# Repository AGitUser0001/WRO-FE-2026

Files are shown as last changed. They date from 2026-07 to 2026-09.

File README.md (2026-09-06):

# Botzilla | WRO 2026 Future Engineers

> [!IMPORTANT]
> **Looking for the full engineering record, photographs, tests, and iterations?** Start with the [Engineering Journal index](docs/00-engineering-journal.md).

## Contents

- [Project abstract](#project-abstract)
- [Team](#team)
- [Challenge overview](#challenge-overview)
- [Requirements and constraints](#requirements-and-constraints)
- [Robot at a glance](#robot-at-a-glance)
- [Overall system architecture](#overall-system-architecture)
- [1. Mobility & Mechanical Design](#1-mobility--mechanical-design)
  - [Final architecture](#final-architecture)
  - [A. Chassis Design Choices](#a-chassis-design-choices)
  - [B. Steering and Drive Mechanism](#b-steering-and-drive-mechanism)
  - [C. Torque and Speed Reasoning](#drive-motor-torque-and-speed)
  - [D. Mechanical Stability and Rigidity](#d-mechanical-stability-and-rigidity)
  - [E. Design Trade-offs, Component Selection, and Iteration](#e-design-trade-offs-component-selection-and-iteration)
- [2. Power & Sensor Architecture](#2-power--sensor-architecture)
  - [A. Power Budget, One-Battery Architecture, and Evidence](#a-power-budget-one-battery-architecture-and-evidence)
  - [B. Sensor and Communication Trade-offs](#b-sensor-and-communication-trade-offs)
  - [C. Placement Proven Against Field Geometry](#c-placement-proven-against-field-geometry)
  - [D. Calibration and a Common Vehicle Coordinate Frame](#d-calibration-and-a-common-vehicle-coordinate-frame)
  - [E. Failure Points and Reliability Iterations](#e-failure-points-and-reliability-iterations)
- [3. Software Architecture & Obstacle Strategy](#software-architecture-obstacle-strategy)
  - [Software modules and runtime chain](#software-modules-runtime)
  - [Two challenge branches of the shared planner](#shared-planner-challenge-branches)
  - [Safety and edge cases](#software-safety-edge-cases)
  - [Parking scope statement](docs/09-parking-strategy.md)
- [4. Systems Thinking & Engineering Decisions](#systems-thinking-engineering-decisions)
  - [Decision record](#decision-record)
  - [Active risks and mitigations](#active-risks-mitigations)
- [5. Reproducibility & GitHub Quality](#reproducibility-github-quality)
  - [Reproduction path](#reproduction-path)
  - [Detailed linked documents](#detailed-document-index)
  - [Software quick start](#software-quick-start)
  - [Demonstration videos](#demonstration-videos)
  - [Current status](#current-status)
  - [License](#license)

---

## Project abstract

This repository documents Botzilla's vehicle for the 2026 World Robot Olympiad (WRO) Future Engineers competition.

---

## Team

**Institution:** Autopilot  
**Competition entry:** WRO Future Engineers, 16–19 years  
**Coach:** Lili Wang

| Team member | Age | Hobbies | Portrait |
|---|---:|---|---|
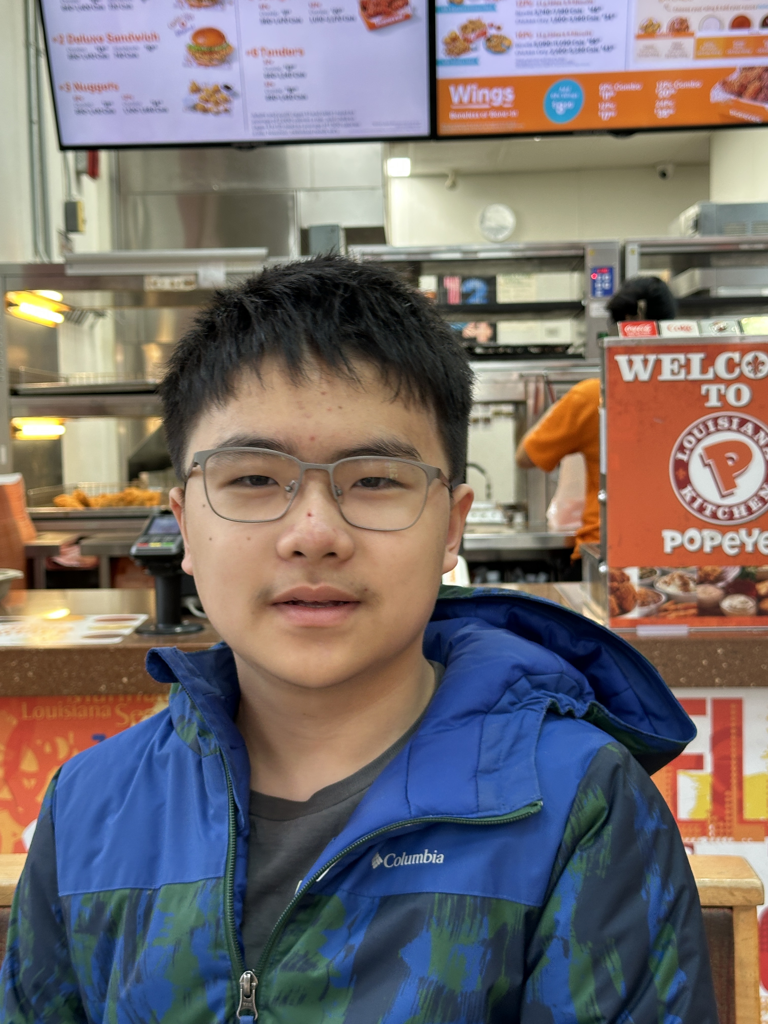
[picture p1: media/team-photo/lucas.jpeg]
Portrait of Lucas Zheng
| Lucas Zheng | 15 | Programming and photography |  |
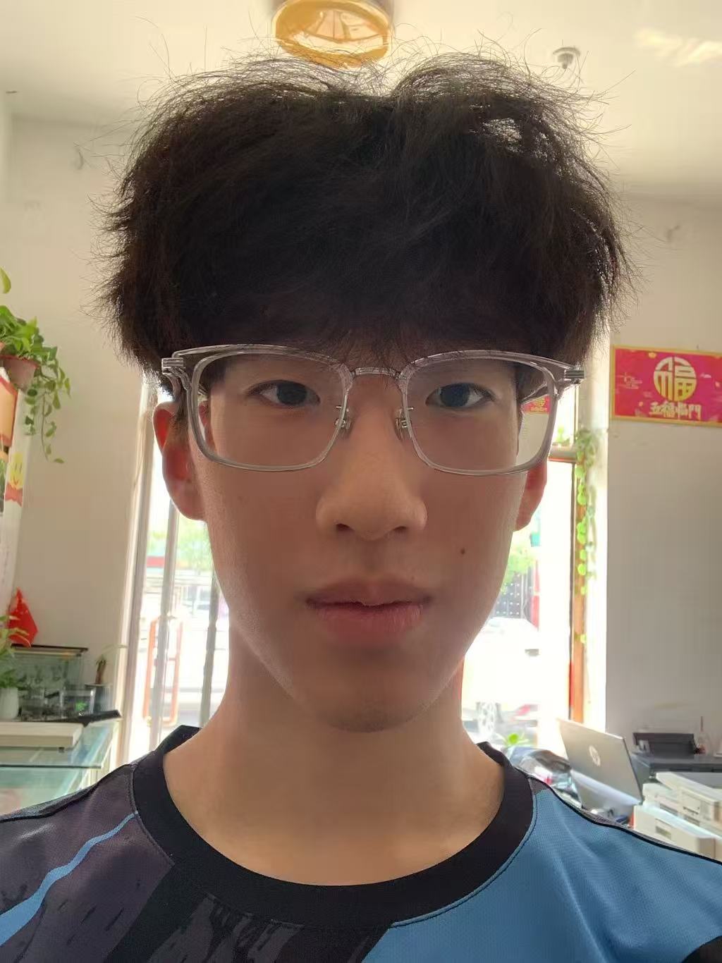
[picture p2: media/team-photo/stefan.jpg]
Portrait of Yueteng Ma
| Yueteng Ma | 16 | Badminton and mathematics |  |
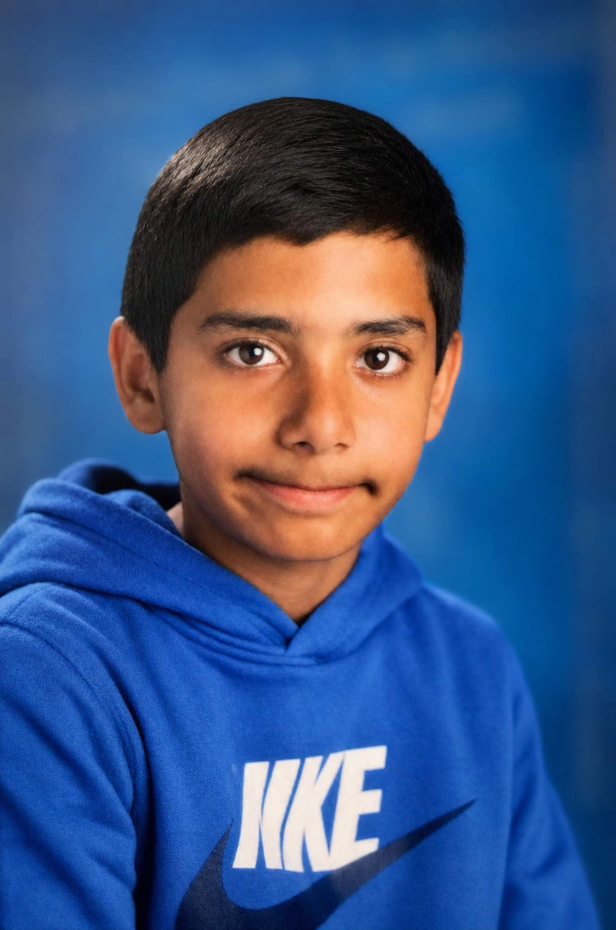
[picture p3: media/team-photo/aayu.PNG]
Portrait of Aayu Mattas
| Aayu Mattas | 14 | General sports and introductory robotics learning |  |

The coach supported learning and organization. The students designed, constructed, programmed, tested, and documented the vehicle.

> [!IMPORTANT]
> **Detailed engineering document:** [Team and Project](docs/01-team-and-project.md) — team identity, members, responsibilities, development method, and project scope.

---

## Challenge overview

### Open Challenge

The robot must complete three laps on the track after being placed randomly inside the walls of the track. One button turns on the robot and one button starts the program. After this, no further interactions with the robot are allowed. See the [Open Challenge Strategy](docs/07-open-challenge-strategy.md).

### Obstacle Challenge

The robot must complete three laps on the track with randomly arranged green and red traffic signs. It must pass on the right side of a red pillar and the left side of a green pillar. See the [Obstacle Challenge Strategy](docs/08-obstacle-challenge-strategy.md).

Learn about the challenges and rules [here](https://wro-association.org/wp-content/uploads/WRO-2026-Future-Engineers-Self-Driving-Cars-General-Rules.pdf).

---

## Requirements and constraints

Competition rules directly shape the vehicle's perception, mechanical, power, and start design: red and green obstacles require camera-based colour recognition; the three-minute run sets the speed, acceleration, and torque budget; one main-power switch and one program-start button define the two permitted operations; and size, mass, drive-layout, and collision constraints shape the vehicle layout and control strategy.

> [!IMPORTANT]
> **Detailed engineering document:** [Requirements and Constraints](docs/02-requirements-and-constraints.md) — how each competition rule becomes an engineering requirement or design constraint.

---

## Robot at a glance

| Attribute | Final value | Evidence |
|---|---:|---|
| Length | 220 mm | [Dimensioned drawing](hardware/mechanical/dimensioned-drawings/README.md) |
| Width | 155 mm | [Dimensioned drawing](hardware/mechanical/dimensioned-drawings/README.md) |
| Height | 158 mm | [Dimensioned drawing](hardware/mechanical/dimensioned-drawings/README.md) |
| Weight | 1,450 g (including competition battery) | [Weight budget](hardware/mechanical/calculations/weight-budget.csv) |
| Drive arrangement | One 12 V GA25-370 Hall-encoder gearmotor (9.6:1 gearbox; 625 rpm maximum no-load gearbox-output speed) drives the shared rear axle through a 20T:40T timing-belt reduction. | [Rules 11.5 and 11.13: rear-drive transmission](docs/04-mobility-and-mechanical-design.md#3-rules-115-and-1113-determine-the-rear-drive-transmission) |
| Steering | Front-mounted SC-1258TG+ servo (`9.6 kgf·cm / 0.10 s/60°` at `4.8 V`), mechanical linkage, and positive Ackermann front steering. | [Servo selection and mechanical design](docs/04-mobility-and-mechanical-design.md#11-steering-servo-torque-and-response-speed-selection) |
| Single-board microcontroller (SBM) | ESP32-S3 and carrier board | [Controller selection and power architecture](docs/05-power-and-sensor-architecture.md#why-esp32-s3-was-selected-as-the-sbm) |
| Single-board computer (SBC) | Jetson Orin Nano Super Developer Kit | [Controller selection and power architecture](docs/05-power-and-sensor-architecture.md#why-jetson-orin-nano-super-developer-kit-was-selected-as-the-sbc) |
| Sensors | Two LDROBOT STL-27L 2D LiDARs, an Intel RealSense D435f depth camera, a Syd Dynamic Transducern TM171 IMU, and the GA25-370 integrated Hall encoder | [Sensor, Cable, and Interface Record](docs/05-power-and-sensor-architecture.md#sensor-cable-and-interface-record) |
| Battery | 12 V 4500 mAh battery | [Power architecture and battery comparison](docs/05-power-and-sensor-architecture.md#battery-capacity-comparison) |
| Software | ESP32 actuator firmware plus Jetson-developed ROS 2 packages for perception, localization, and decision-making, using vendor ROS 2 driver packages | [Software architecture](docs/06-software-and-control-architecture.md) |

---

## Overall system architecture

```mermaid
flowchart LR
    S[Camera / distance sensors / IMU / encoder] --> P[Perception and state estimation]
    P --> D[Decision state machine]
    D --> C[Steering and speed control]
    C --> A[Drive motor and steering actuator]
    A --> V[Vehicle motion]
    V --> S
    B[Battery and regulated power rails] --> S
    B --> P
    B --> C
    L[Logging and telemetry] --- P
    L --- D
    L --- C
```

> [!IMPORTANT]
> **Detailed engineering document:** [System Architecture](docs/03-system-architecture.md) — physical connections, ROS 2 topics and data flows, update rates, voltage domains, communication protocols, coordinate conventions, and failure behaviour.

---

# 1. Mobility & Mechanical Design

## Final architecture

### Current physical vehicle layout

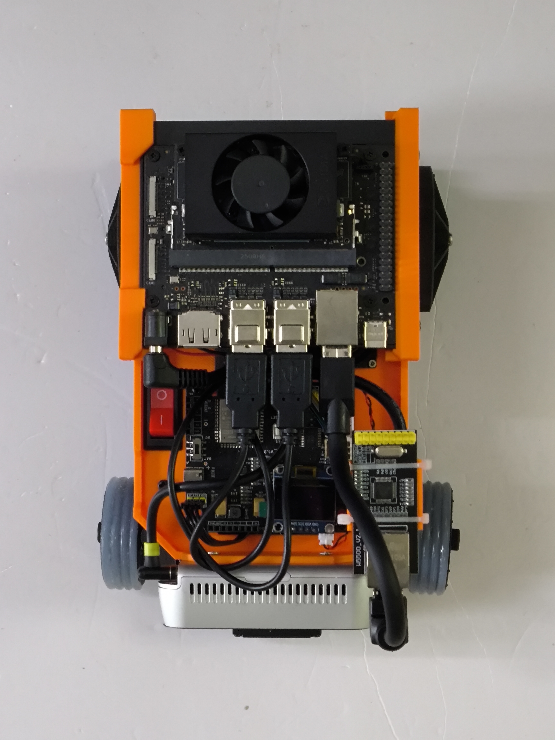
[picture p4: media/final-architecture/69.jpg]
Top view of the current 2026 vehicle, showing the component layout across the multi-layer chassis.


| Side A | Front sensor layout | Side B |
|---|---|---|
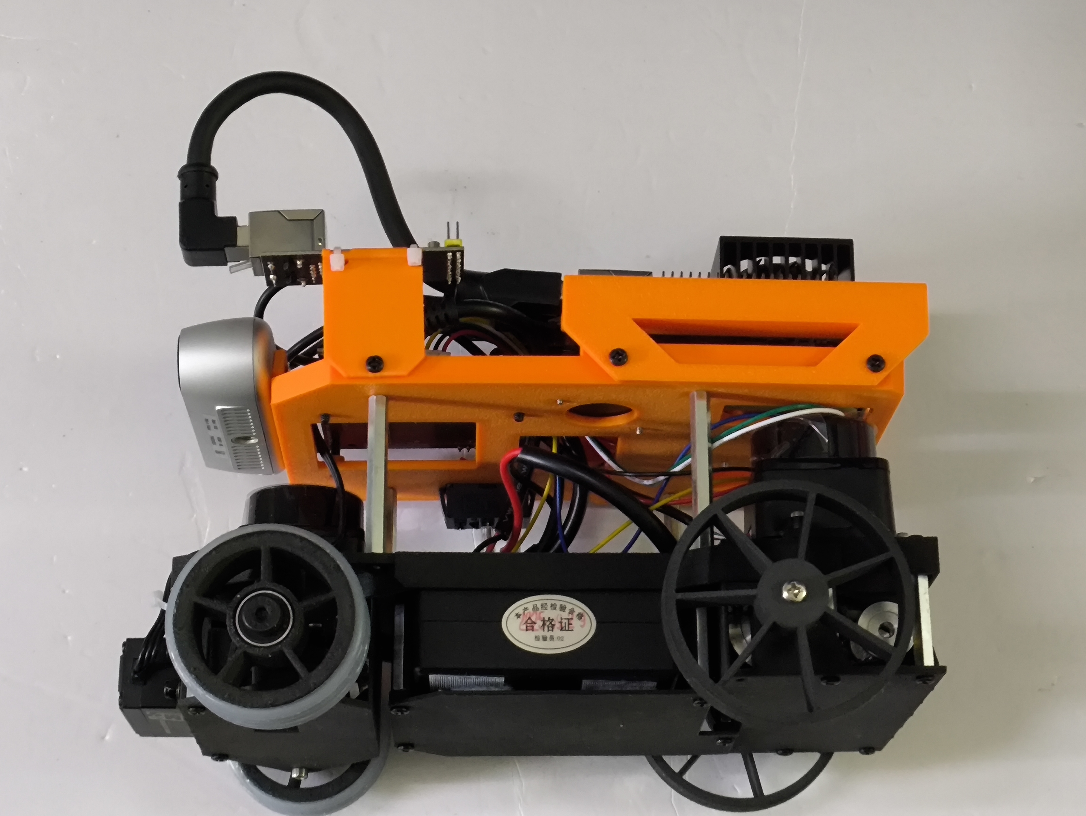
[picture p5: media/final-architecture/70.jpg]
First side view of the current 2026 vehicle.
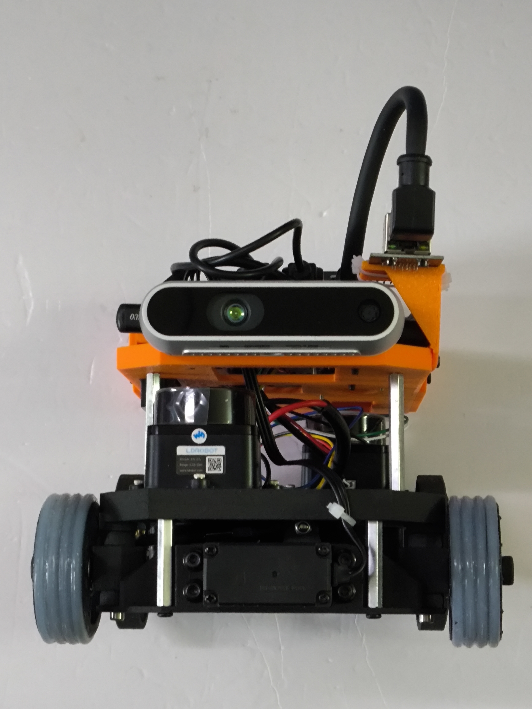
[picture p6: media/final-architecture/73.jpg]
Front view of the current 2026 vehicle, showing the forward-facing sensor arrangement.
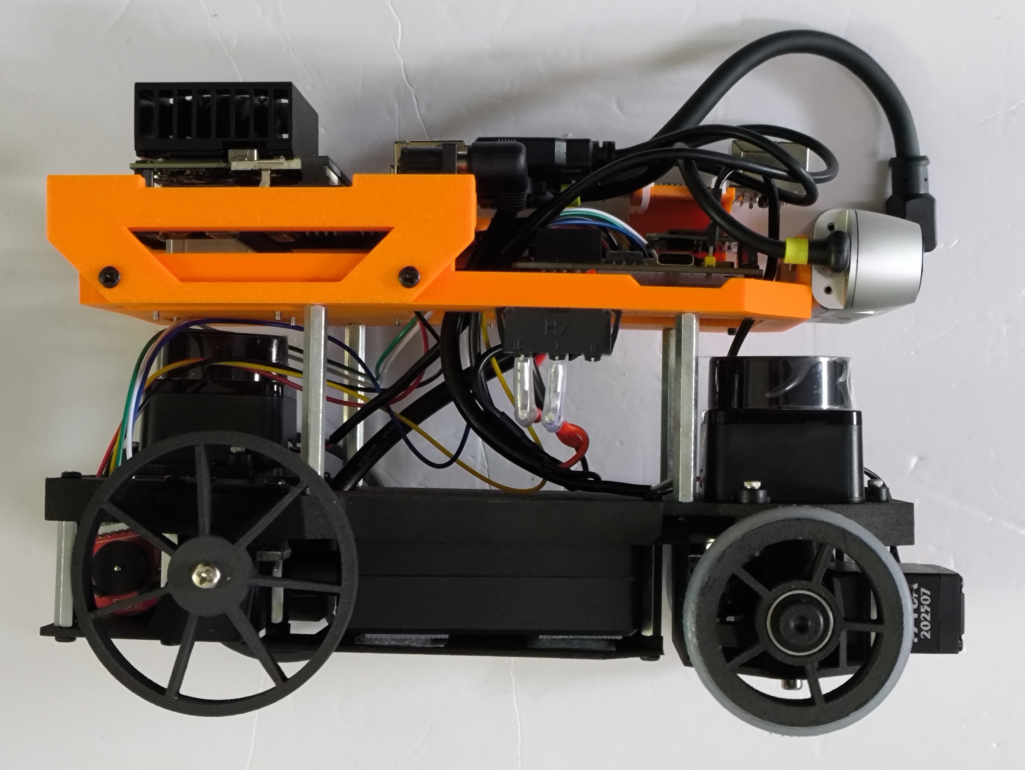
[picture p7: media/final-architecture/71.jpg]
Second side view of the current 2026 vehicle.
|  |  |  |

| Rear drive layout | Bottom chassis layout |
|---|---|
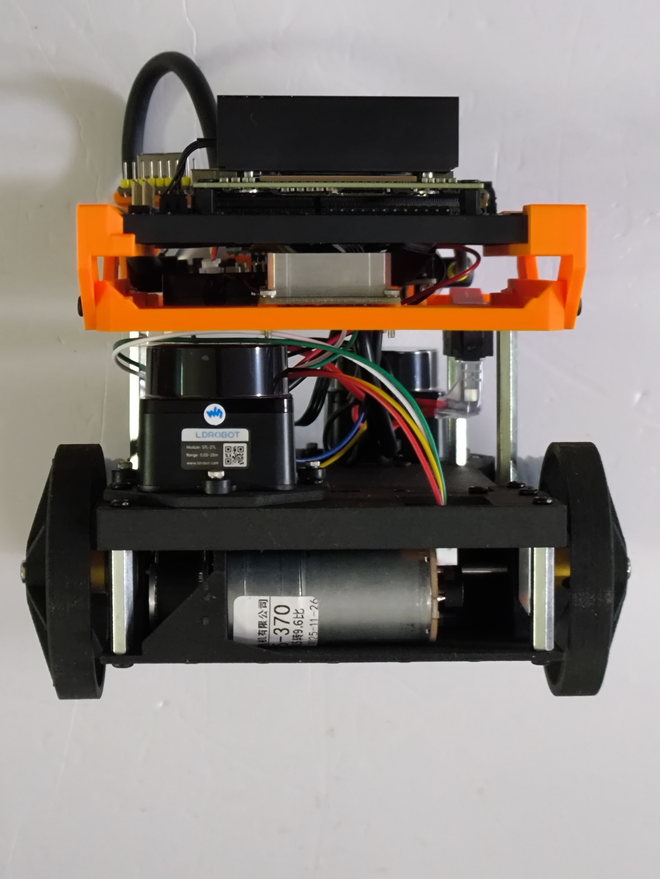
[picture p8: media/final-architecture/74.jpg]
Rear view of the current 2026 vehicle, showing the rear drive area.
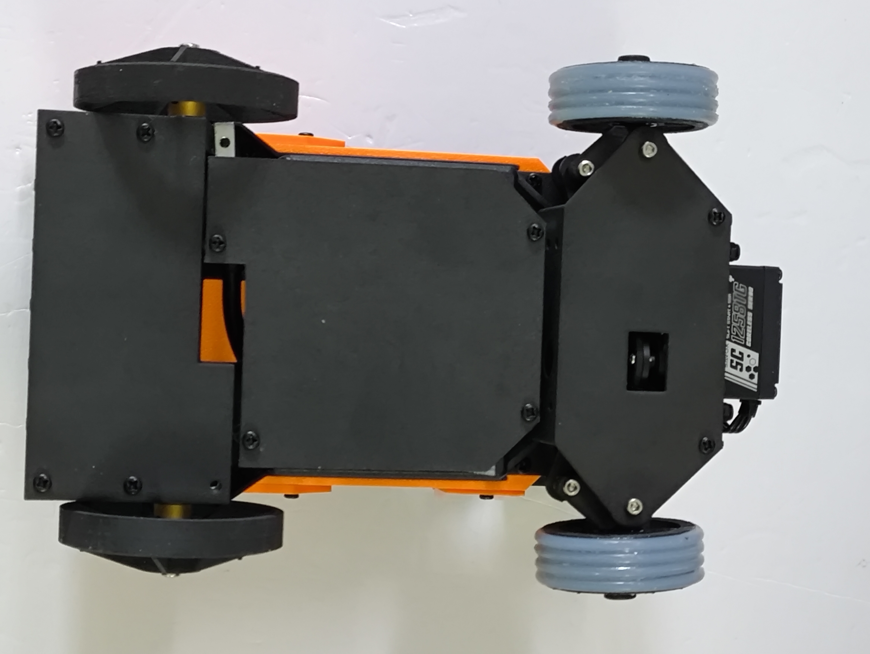
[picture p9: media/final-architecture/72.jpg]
Bottom view of the current 2026 vehicle, showing the chassis and wheel layout.
|  |  |

### Architecture summary

**Final layout:** a custom three-level 3D-printed chassis that separates the mechanical, sensing/battery, and computing/wiring functions.

- **Lowest layer:** front steering, rear drive, and the battery structure remain low in the vehicle.
- **Middle layer:** the battery bay and both LDROBOT STL-27L 2D LiDAR scan planes have defined mounting positions.
- **Upper layer:** the ESP32-S3 single-board microcontroller (SBM), Jetson Orin Nano Super Developer Kit single-board computer (SBC), perception hardware, and all cross-layer wiring remain above the vehicle perimeter.

#### Lowest layer — protected steering, drive, and battery structure

- **Ground clearance: 7 mm.** The original target was 20 mm. The final course surface is smooth and fixed, so lowering the chassis reduces the centre of gravity and preserves vertical space for electronics. The trade-off is that the bottom must remain clear of floor contact.

- **Protected lower structure.** Custom 3D-printed upper and lower plates protect the front and rear mechanical modules; intentional openings remain only for fasteners, steering links, wheel pivots, and motor/axle interfaces. The central space is reserved for the battery, and pre-designed holes provide the mounting and cable-routing interfaces for the layers above.

- **Front axle — physical steering chain.**
  - The servo is bolted into a printed front-axle cradle below the upper plate; it does not turn the wheels directly.
  - **Motion path:** servo output spline → supplied teardrop-shaped servo disc → printed teardrop capture/adapter → printed steering horn → ball-joint drag link → adjustable three-part tie rod → left/right steering arms → steering knuckles → wheel stub axles and hubs.
  - The threaded centre section of the three-part tie rod adjusts its effective length while the rod-end joints remain free to articulate.
  - Each printed steering cup pivots around a vertical kingpin between the chassis plates; its horizontal stub axle carries a freely rolling front wheel and hub.
  - The steering-arm pickup points angle inward toward the rear axle. Servo push-pull motion therefore turns the inner cup farther than the outer cup, creating the selected positive-Ackermann geometry mechanically rather than through software differential.

| Servo mount below the upper plate | Servo and steering-linkage path |
|---|---|
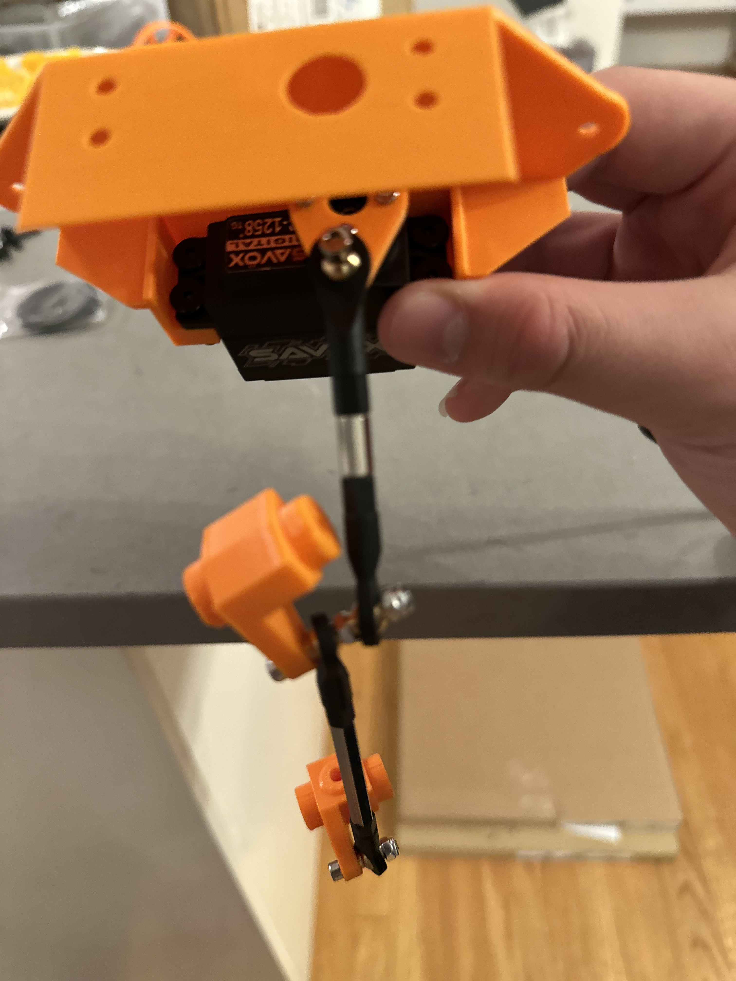
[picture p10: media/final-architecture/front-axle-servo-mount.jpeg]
Servo installed inside the printed front-axle module.
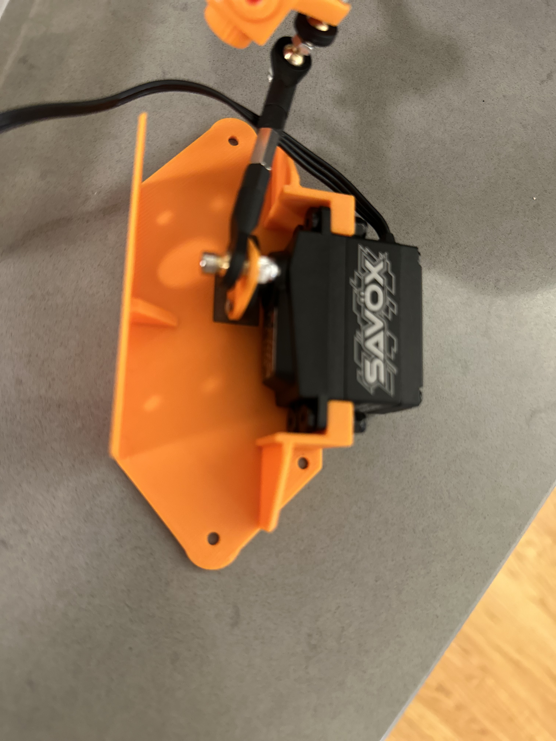
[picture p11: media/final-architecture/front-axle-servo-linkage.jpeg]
Servo, horn, and steering linkage mounted to the front-axle plate.
|  |  |

| Linkage assembly before enclosure | Protected lower front-axle module |
|---|---|
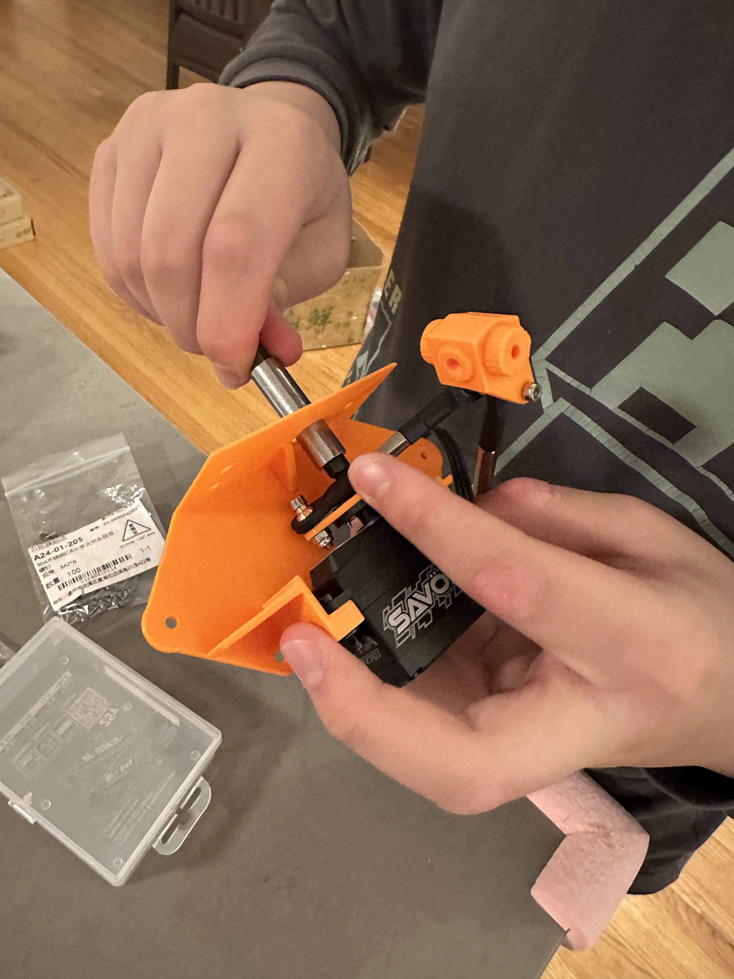
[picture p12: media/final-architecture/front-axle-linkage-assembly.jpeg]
Front steering linkage assembly in the printed module.
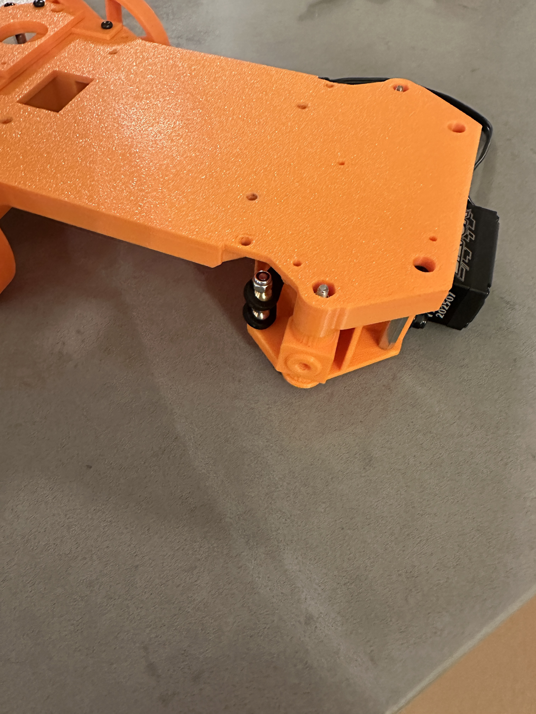
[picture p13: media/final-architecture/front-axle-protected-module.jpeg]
Lower plate and protected front-axle module, with pivot interface visible.
|  |  |

- **Rear axle — physical drive chain.**
  - The external transmission is a timing-belt reduction, not a train of meshed spur gears.
  - The GA25-370 Hall-encoder gearmotor sits in a printed cradle with two slotted mounting holes. A 20-tooth timing pulley is fixed to the output shaft of its internal 9.6:1 gearbox.
  - **Motion path:** DC motor rotor → internal 9.6:1 gearbox → 20-tooth timing pulley → timing belt → 40-tooth timing pulley → transverse rear axle → left/right wheel hubs.
  - The large pulley is fixed to the transverse rear shaft. That shaft passes through two printed supports and connects to brass hex wheel couplers secured with set screws; one common shaft therefore gives both rear wheels the same angular speed.
  - The external 40 ÷ 20 = **2:1** reduction halves axle speed and approximately doubles available axle torque, subject to belt efficiency. The nominal motor-rotor-to-rear-axle reduction is **9.6 × 2 = 19.2:1**.

- **Belt-tension procedure.**
  1. Leave the two motor-mount screws loose so the motor can slide in its elongated slots.
  2. Align the small pulley with the large pulley, fit the belt, and use the tension screws to set the motor position.
  3. Rotate the output shaft by hand and compare belt deflection with the established rear-axle setup.
  4. Tighten the motor-mount screws, then perform the powered drive check.

| 1. Motor slides in the tensioning slots | 2. Small pulley aligned and locked to the motor D shaft |
|---|---|
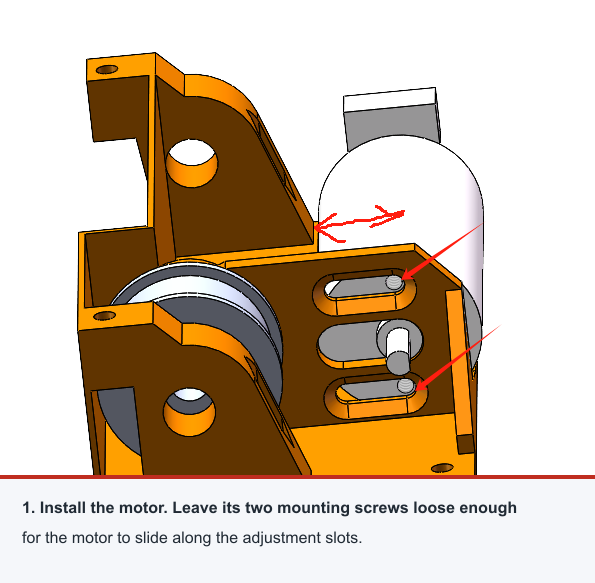
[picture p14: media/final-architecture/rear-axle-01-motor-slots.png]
Motor mounted with screws loose enough to slide along the tensioning slots.
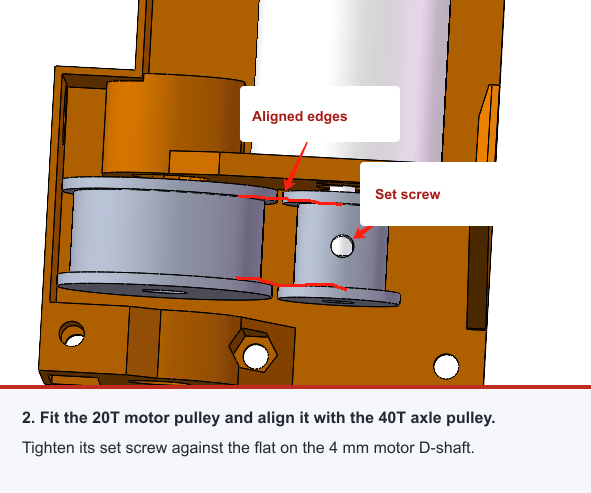
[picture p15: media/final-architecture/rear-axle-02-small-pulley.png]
Small timing pulley aligned with the large pulley and fixed by a set screw on the motor shaft flat.
|  |  |

| 3. Toothed belt installed around the two pulleys | 4. Belt tension adjusted before the motor mount is locked |
|---|---|
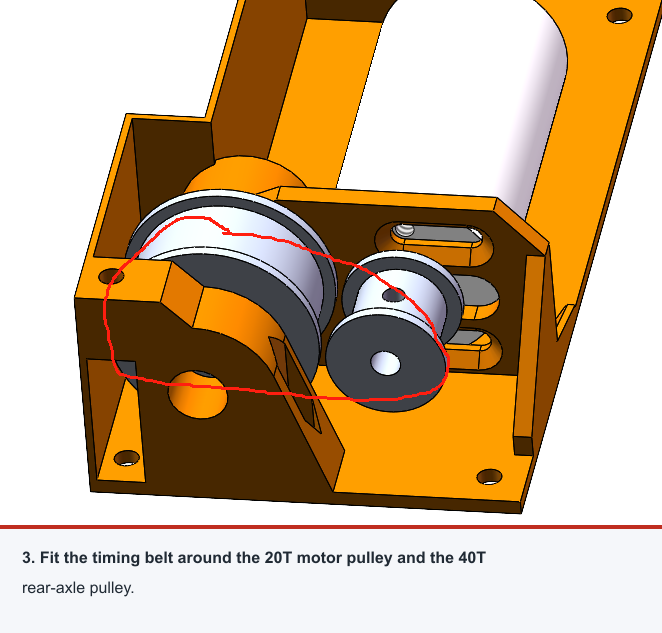
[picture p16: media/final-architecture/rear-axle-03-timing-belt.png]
Timing belt loop fitted around the large driven pulley and small motor pulley.
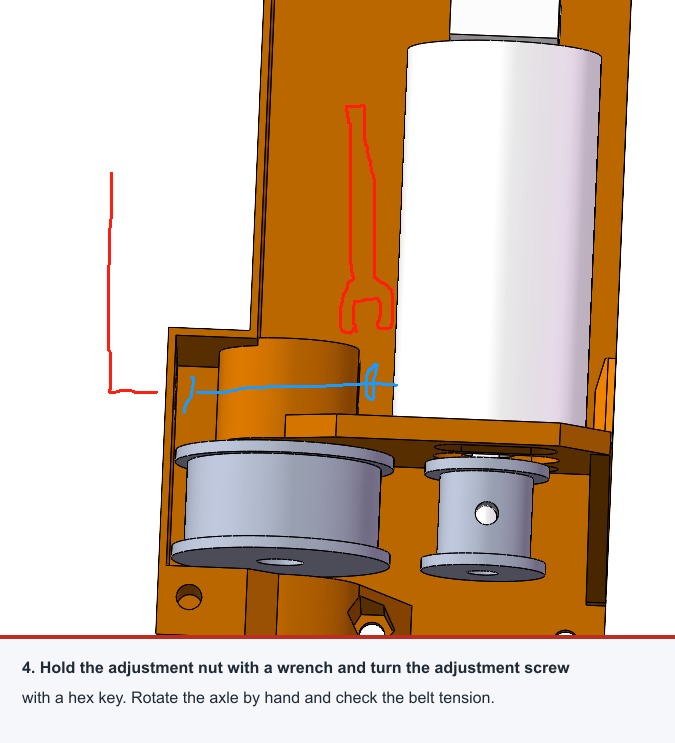
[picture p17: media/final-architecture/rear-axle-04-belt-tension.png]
Rear-axle belt-tension adjustment using the motor-slot and adjustment screw.
|  |  |

| 5. Motor screws tightened after a manual and powered check | |
|---|---|
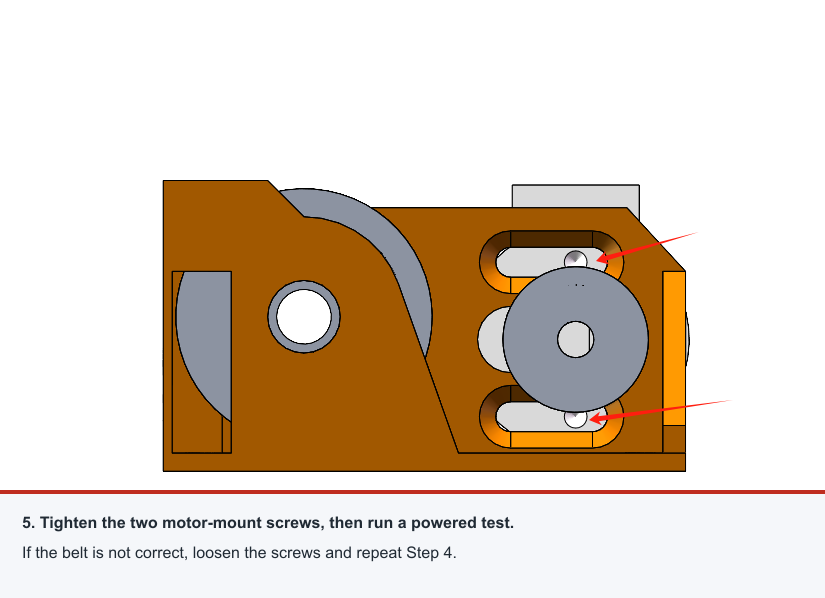
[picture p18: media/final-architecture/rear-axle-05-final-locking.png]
Motor fixed after belt tension adjustment, ready for a powered verification.
|  | |

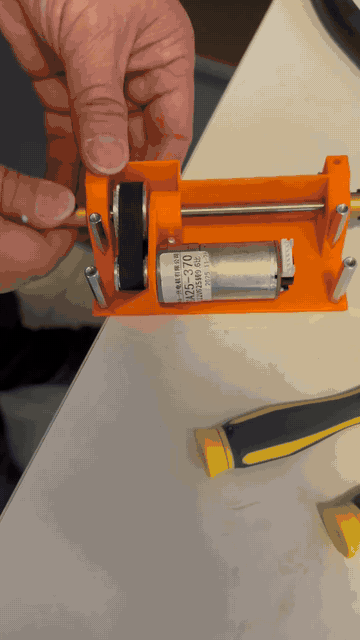
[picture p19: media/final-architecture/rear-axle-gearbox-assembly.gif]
Animated rear-axle assembly: GA25-370 motor, small driving pulley, timing belt, large driven pulley, supported transverse axle, and wheel interfaces.


**Rear-drive assembly check:** As shown in the animation, manually turn the transmission after assembly. Confirm that the 20T driving pulley, timing belt, 40T driven pulley, rear axle, and both rear wheels move smoothly together; check that the belt does not bind or visibly track sideways and that both wheels turn with the shared axle.

#### Middle layer — battery bay and LiDAR scan plane

- **Battery and service access.** The centre remains available for the battery and wiring rising from the lower module. Brass double-ended threaded standoffs join the printed layers while retaining access for service.

- **2D LiDAR scan geometry.**
  - Two lightweight 2D LiDARs were selected instead of a heavier 3D LiDAR within the vehicle mass budget.
  - Both scan planes are below **95 mm**, allowing them to intersect approximately 100 mm-high course walls and obstacles.
  - The front LiDAR is upright; the rear LiDAR is inverted and offset longitudinally. Software fuses the two scans into one obstacle representation.
  - Wiring between the LiDARs, battery bay, and upper electronics remains inside the chassis footprint.

#### Upper layer — computing, perception, and protected wiring

- **Open, serviceable structure.** The upper structure is intentionally open rather than enclosed, so all cross-layer connections terminate above the vehicle perimeter rather than hanging from its sides.

- **Computing and sensing layout.**
  - The layer carries the ESP32-S3, its carrier board, and the speaker.
  - Raised rear mounts carry the IMU and Jetson Orin Nano Super Developer Kit; viewed from the rear, the high white button on the left is the GPIO-connected program-start button.
  - The depth camera sits on the forward centreline.
  - A raised platform on the vehicle's right carries the W5500 wired-Ethernet interface connecting Jetson and ESP32. This avoids Wi-Fi during competition and the instability previously observed with USB serial.

#### Actuator selection and verification plan

- **Steering servo.** The high-torque candidate was **SC-1256TG** (`16.0 kgf·cm / 0.18 s/60°` at `4.8 V`); the final candidate was **SC-1258TG+** (`9.6 kgf·cm / 0.10 s/60°` at `4.8 V`). We selected SC-1258TG+ because its torque still covers the steering calculation while its faster response better supports timely low-speed steering corrections. [Candidate comparison and torque calculation](docs/04-mobility-and-mechanical-design.md#11-steering-servo-torque-and-response-speed-selection).

- **Drive motor.** The GA25-370 uses a **9.6:1** gearbox. The calculation below converts the 6,000 rpm motor specification, internal gearbox, external 20T-to-40T belt reduction, and confirmed **65 mm** physical rear-tyre diameter into a no-load speed boundary for the transmission. It only checks that the motor speed and gearing do not limit the planned average speed or measured steady speed; the torque requirement is calculated separately in [C. Torque and Speed Reasoning](#drive-motor-torque-and-speed).

**No-load speed boundary for the transmission (not the vehicle's real top speed)**

$$
n_{\text{gearbox}} = \frac{6000}{9.6} = 625\ \text{rpm}
$$

$$
n_{\text{rear axle}} = \frac{625}{2} = 312.5\ \text{rpm}
$$

$$
v_{\text{no-load upper bound}}
= \frac{\pi \times 0.065 \times 312.5}{60}
\approx 1.06\ \text{m/s}
$$

**Why this check matters:** **1.06 m/s** is a kinematic upper bound for an unloaded, ideal transmission; it is not a claimed on-course speed. The planned average speed is **0.14 m/s** and the mean steady speed in the straight-line vehicle test is **0.319 m/s**, both below this boundary. The selected motor speed and **20T:40T** reduction therefore leave speed margin for low-speed course driving. Actual speed must still be confirmed in loaded vehicle tests.

---

## A. Chassis Design Choices

#### Design starting point: lessons from the 2025 vehicle

##### 2025 vehicle: problem baseline

| Original course setting | Three-quarter vehicle view |
|---|---|
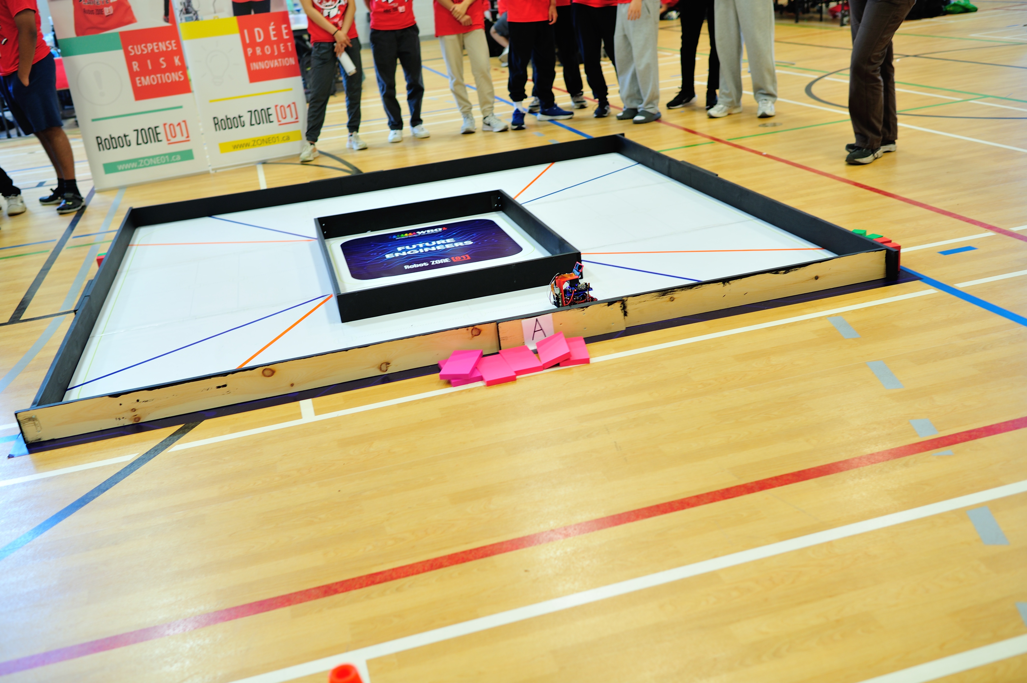
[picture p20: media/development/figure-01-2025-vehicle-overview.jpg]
2025 vehicle in its original course setting.
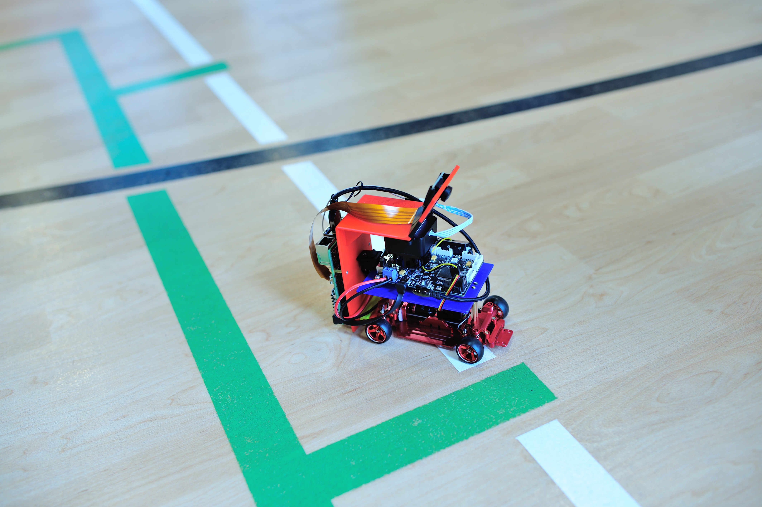
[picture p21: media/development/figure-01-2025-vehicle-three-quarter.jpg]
2025 vehicle, three-quarter view.
|  |  |

- **Starting point:** the 2025 vehicle was built by adapting RC-car parts.
- **Observed result:** it completed important development work, but its mechanical layout limited parking, sensing, and obstacle runs.
- **2026 decision:** convert those observed failures into chassis requirements rather than relying on software alone to compensate for them.

#### Requirements derived from the 2025 vehicle

| 2025 observation | Effect on competition performance | 2026 chassis requirement |
|---|---|---|
| The parallel-steering layout needed several manoeuvres to leave the parking area; it could not make the desired large, continuous turn. Other teams' Ackermann-steered vehicles showed that a single-turn exit could be possible. | Parking exit was slow and inconsistent. | The front axle must support a large, repeatable mechanically steered turn. Ackermann geometry is evaluated in [Steering and Drive Mechanism](#b-steering-and-drive-mechanism). |
| Exposed cables had no defined routing or strain relief. | A cable could be dragged into an obstacle and end a run. | Provide protected cable routes, attachment points, and connector strain relief in the chassis design. |
| A fisheye camera was mounted at an angle on a red roof. It did not provide depth, its distorted image required software correction, and strong sunlight could overexpose the image. | Perception could become unreliable in bright conditions. | Give the depth camera a repeatable mounting position, viewing angle, cable route, and provision for controlling direct light. |
| No LiDAR mounting position or scan volume was designed into the chassis. The sensor was later installed inverted in the middle of the vehicle, where its returns were unreliable. | LiDAR data could not be used reliably in the 2025 solution. | Reserve a defined LiDAR mounting surface, orientation, cable route, and unobstructed scan area from the first chassis design. |
| The plastic transmission gear between the motor and bearing repeatedly wore and failed five times; replacement parts subsequently could not be purchased. | A critical rear-drive component could make the vehicle unrepairable, reducing debugging and competition availability. | Use metal timing pulleys and a timing belt at the critical motor-to-rear-axle transmission, rather than a plastic gear that cannot be reliably replaced. |

- **Retained construction choice:** brass double-ended threaded standoffs reliably connected multiple structural levels in 2025.
- **2026 use:** retain the standoffs between redesigned 3D-printed layers, while changing the shape and purpose of each layer.

#### Reference platform evaluated in 2026

##### 2026 reference platform

| Overview | Right-side view |
|---|---|
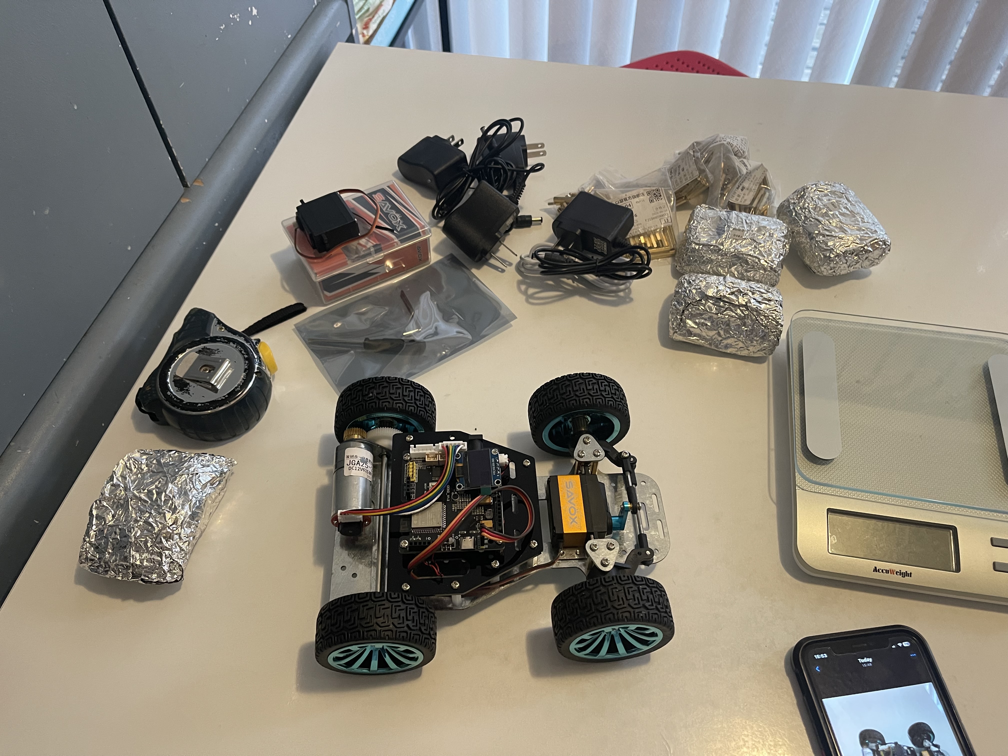
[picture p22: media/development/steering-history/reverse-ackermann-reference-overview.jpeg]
2026 reference platform overview.
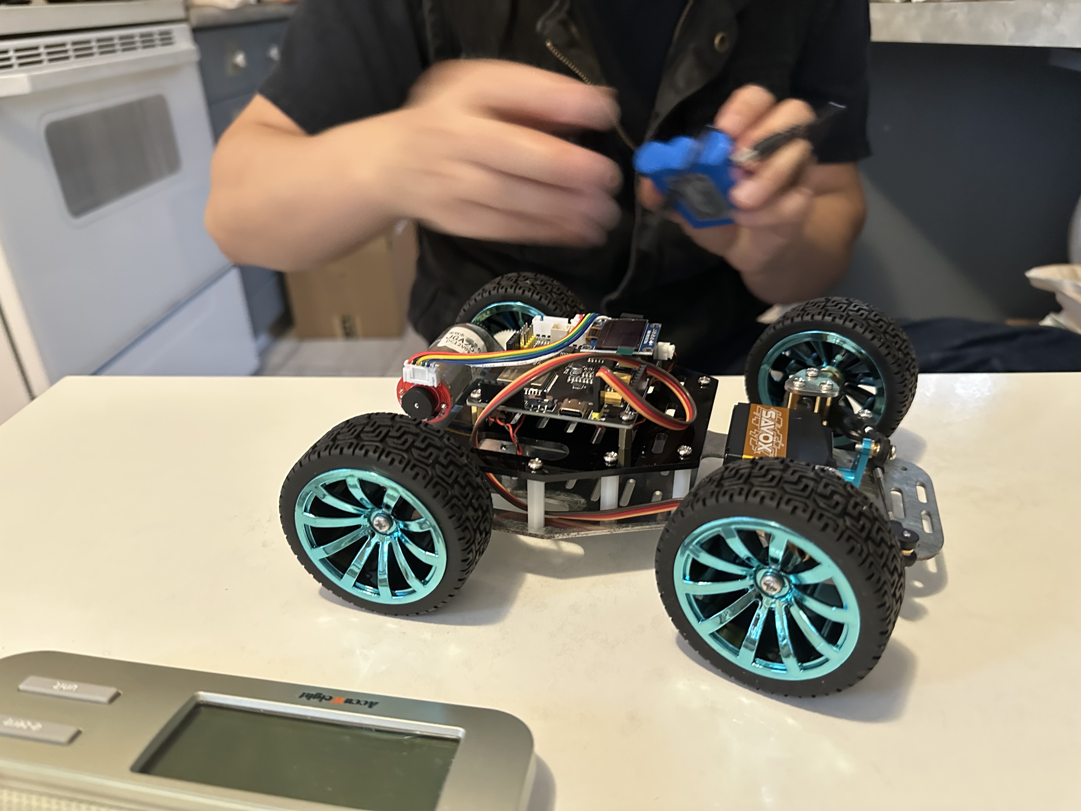
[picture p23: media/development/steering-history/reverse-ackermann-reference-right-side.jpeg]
2026 reference platform, right-side view.
|  |  |

| Front servo and battery display | Steering assembly |
|---|---|
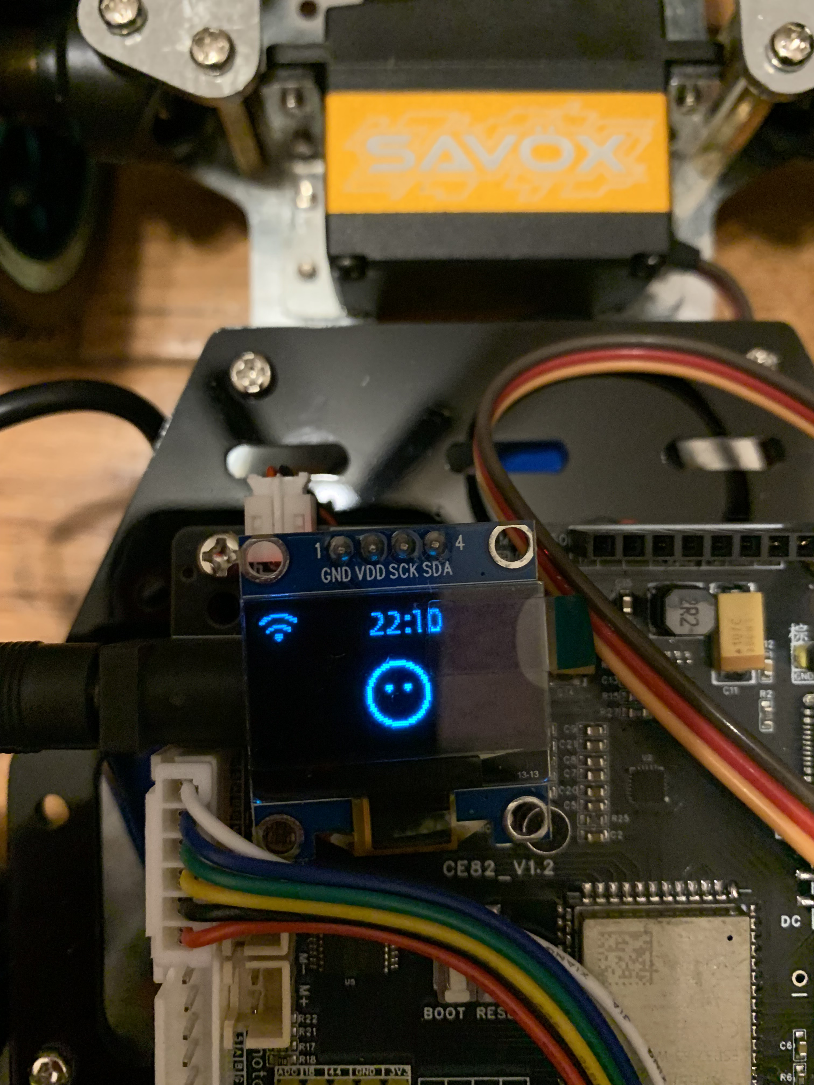
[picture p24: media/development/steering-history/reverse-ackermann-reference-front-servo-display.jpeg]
2026 reference platform front servo and battery display.
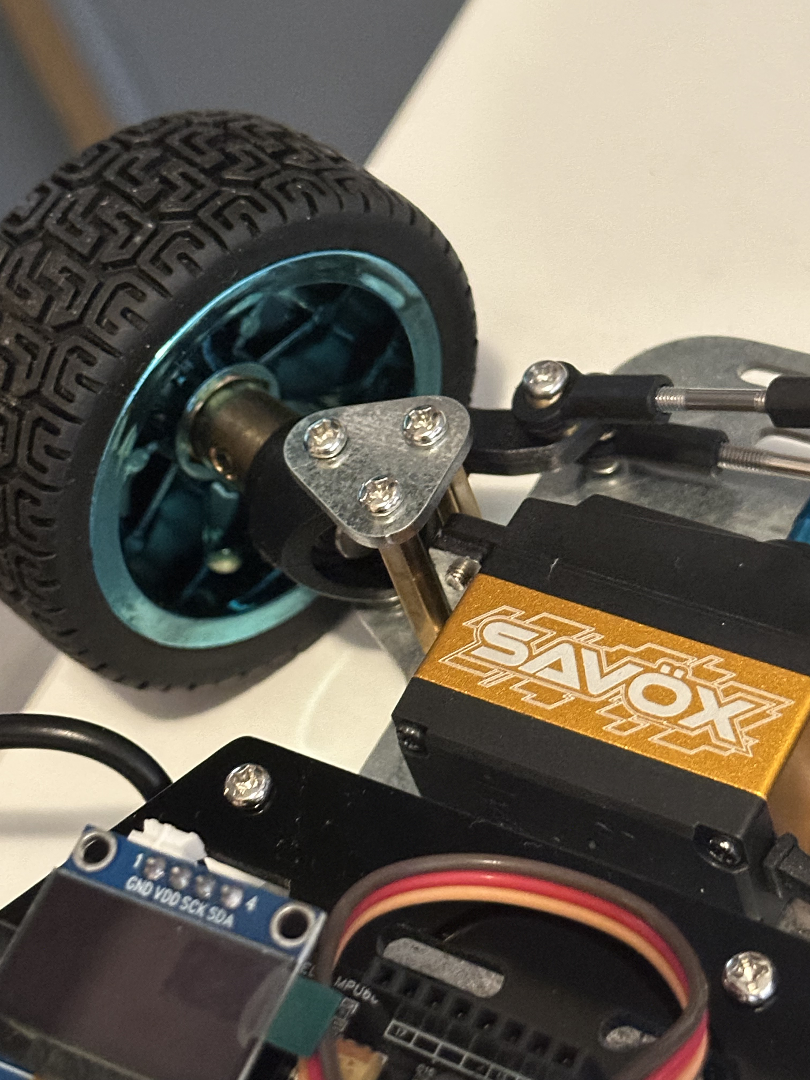
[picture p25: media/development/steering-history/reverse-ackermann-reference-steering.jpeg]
2026 reference platform steering assembly.
|  |  |

| Front-axle servo and steering detail | Rear wheel and bearing | Drive motor |
|---|---|---|
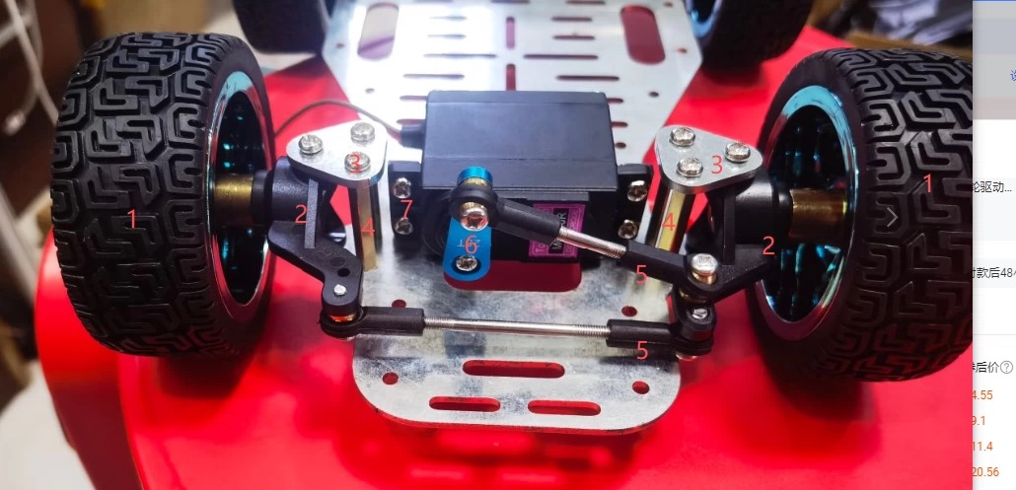
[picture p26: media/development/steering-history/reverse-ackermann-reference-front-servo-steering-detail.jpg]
2026 reference platform front-axle servo and steering detail.
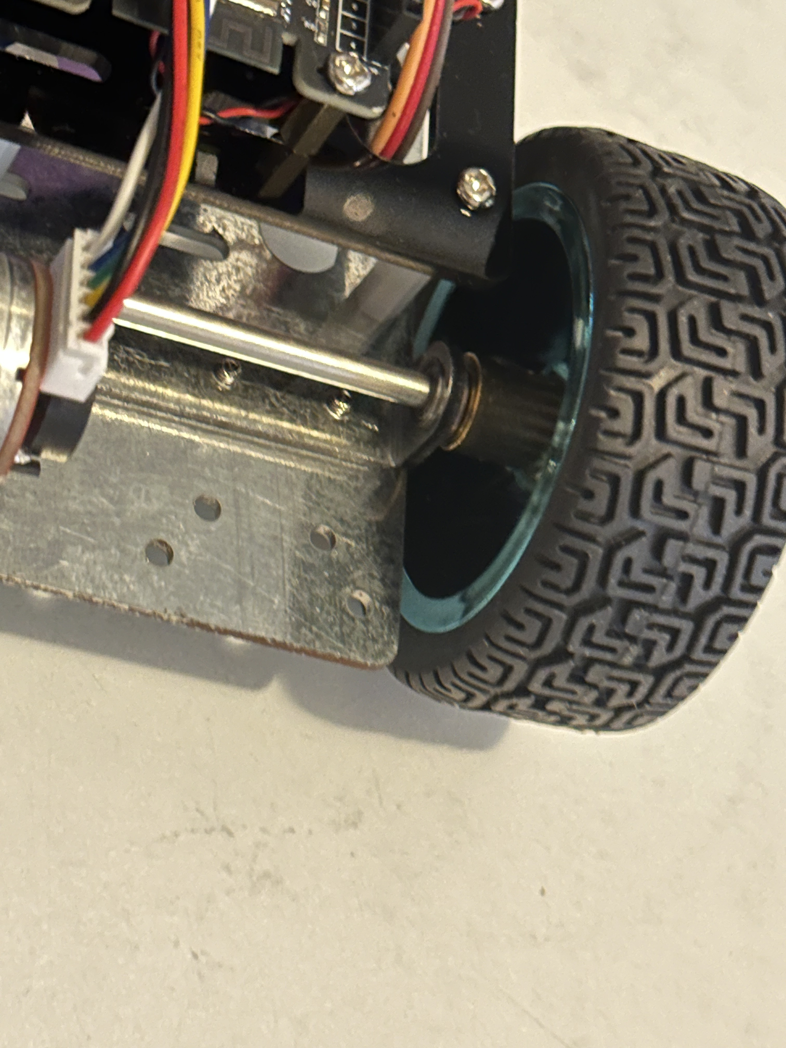
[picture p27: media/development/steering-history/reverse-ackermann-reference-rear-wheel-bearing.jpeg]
2026 reference platform rear wheel and bearing.
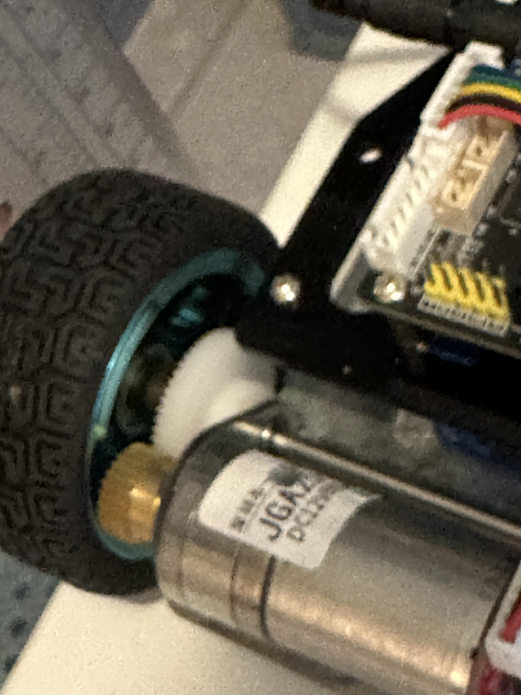
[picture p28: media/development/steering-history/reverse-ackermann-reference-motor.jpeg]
2026 reference platform drive motor.
|  |  |  |

*This 2026 reference platform is a mechanical-layout reference, not the final competition vehicle; the photographs record its overall layout, right side, front-axle servo and steering assembly, rear wheel/bearing, and drive motor.*

- **Role:** an off-the-shelf mechanical reference only, not the final competition vehicle.
- **What it demonstrated:** one motor driving a supported rear axle; a servo steering the front axle through a servo link and a tie rod synchronising the left and right wheels.
- **What it confirmed:** a mechanically driven rear axle and mechanically linked front steering can be packaged in a small vehicle without steering by independently varying left and right drive motors.
- **Why it was not adopted:** it did not provide enough deck area or a practical multi-layer layout for our camera, LiDARs, battery, controllers, and protected wiring.
- **How it informed the final design:** the steering-geometry evaluation and the different geometry selected for the final vehicle are explained in [Steering and Drive Mechanism](#b-steering-and-drive-mechanism).

#### Final chassis concept and iterations

- **Custom chassis objective:** defined sensor locations, protected cable management, and mounting interfaces for the steering and drive modules.
- **Packaging constraint:** fit the complete vehicle through the internal 375 mm narrow-corridor target with safety clearance.
- **Design balance:** minimise the complete swept envelope while retaining enough area for required components and a rigid, serviceable structure; the goal was not simply the smallest theoretical turning radius.

**Development sequence.** In October 2025, V1 first set a `280 mm` theoretical radius, a `145 mm` wheelbase, and large-angle front-wheel steering around the question “can the vehicle leave the parking area in one turn?” The team then found that total vehicle length, front overhang, and tyre sweep constrained the `375 mm` course more than radius alone. It therefore shortened the body, wheelbase, and front overhang, while re-arranging the LiDARs, battery, harnesses, and rear wheels. The chassis was not a board on which components were simply placed: after every geometry change, the team re-checked mounting space and driving effects.

##### Final vehicle dimensions

- **Final vehicle dimensions:** **220 mm long × 155 mm wide × 158 mm high**.

##### Final rear-drive hardware

| Rear-drive assembly | GA25-370 motor and pulley | Timing belt and driven pulley |
|---|---|---|
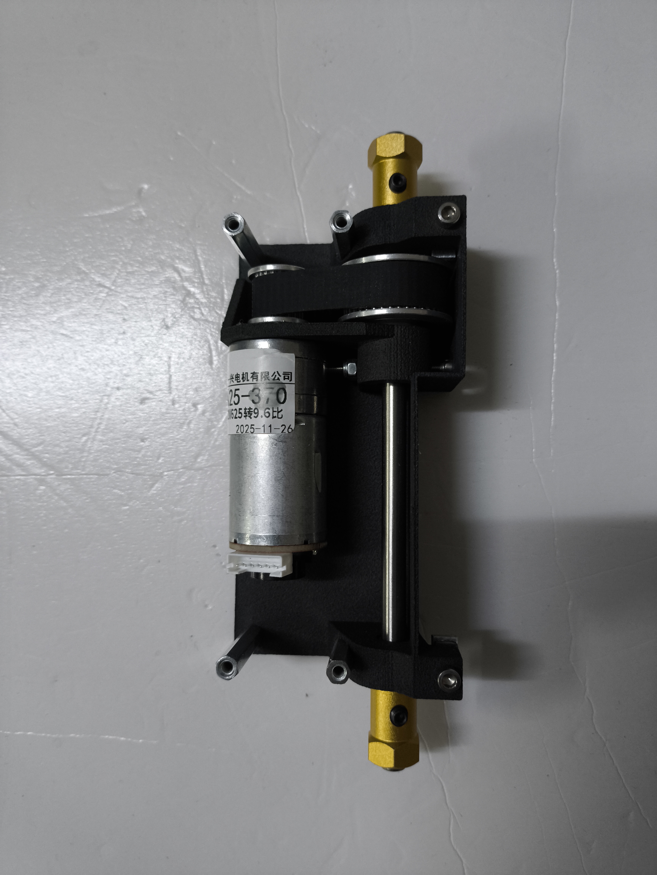
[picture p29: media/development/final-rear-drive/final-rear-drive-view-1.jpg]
Final rear-drive assembly: GA25-370, timing belt, pulleys, and shared rear axle.
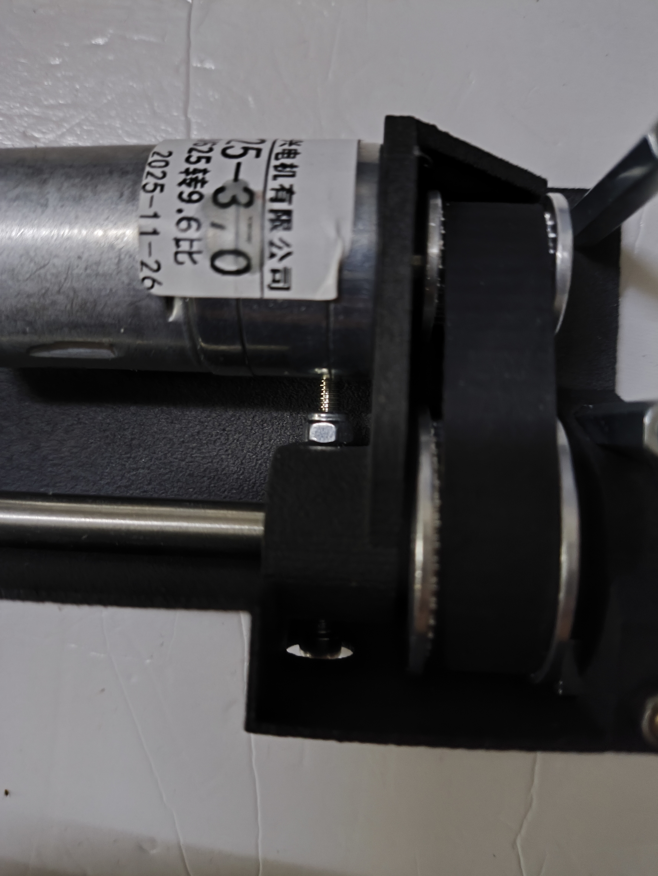
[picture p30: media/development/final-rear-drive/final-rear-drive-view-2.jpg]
Close view of GA25-370, mount, and pulley in the final rear drive.
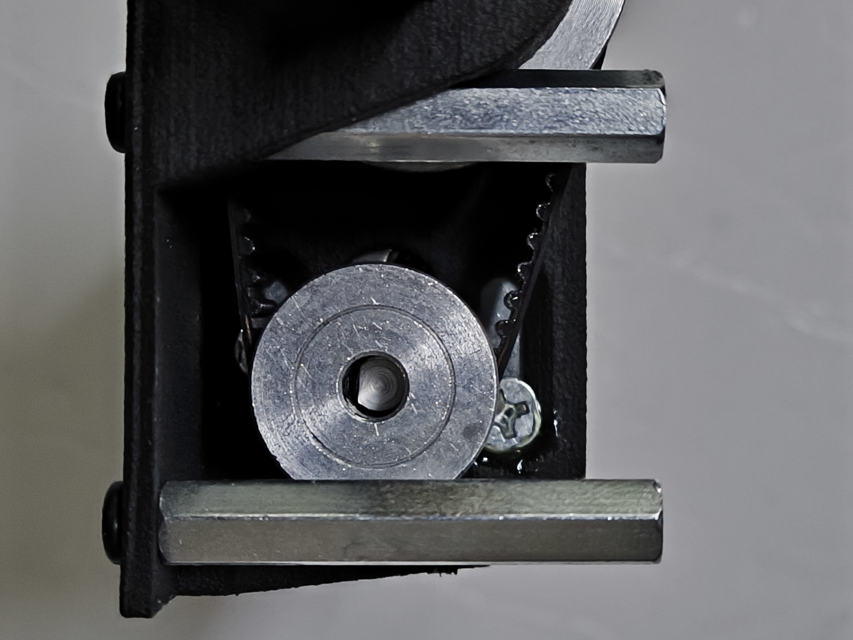
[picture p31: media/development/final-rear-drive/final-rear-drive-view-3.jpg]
Close view of timing belt and driven rear-axle pulley in the final rear drive.
|  |  |  |

*The GA25-370 drives the shared rear axle through metal timing pulleys and a timing belt; the three photographs show the complete assembly, motor side, and belt/pulley side.*

- **Visible evidence:** the large rear-axle pulley and small motor pulley are connected by the timing belt; the motor mount and fasteners allow the belt tension to be adjusted.
- **Vehicle correspondence:** this rear-drive assembly is the one used by the rear-drive parts, transmission calculation, and physical-running discussion below.
- **Course constraint:** 375 mm is measured from the team's own course layout, shown below.
- **Stress case:** the tightest intended continuous turn; actual competition driving can still include a sequence of arcs and corrections.
- **Decision metric:** complete swept envelope — body dimensions, front/rear overhang, wheel track, and outer-wheel sweep — rather than theoretical rear-axle radius alone. See [Steering and Drive Mechanism](#b-steering-and-drive-mechanism).

##### Course geometry reference and 375 mm design constraint

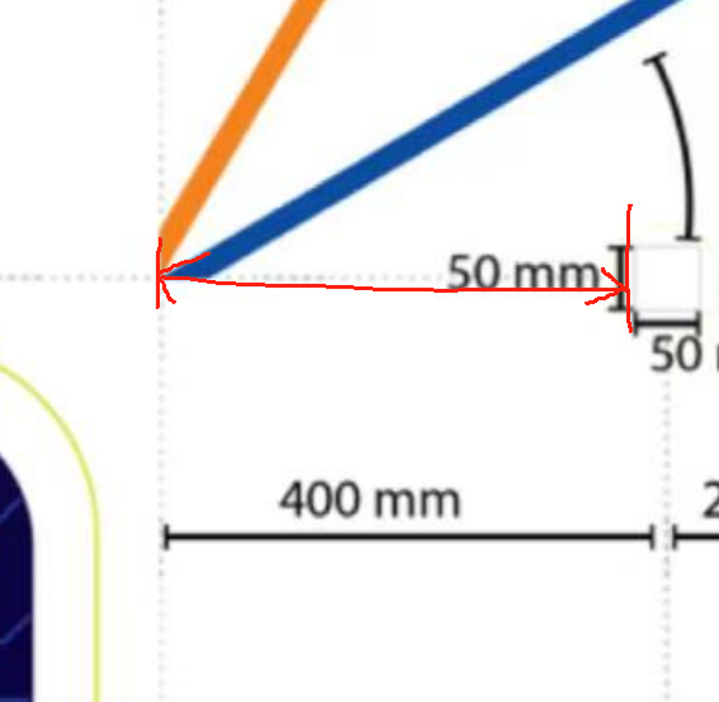
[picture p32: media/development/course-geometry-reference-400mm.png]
Local course-drawing geometry reference, showing the 400 mm distance and 50 mm dimension.


- **Drawing input:** this local course drawing supplies the `400 mm` and `50 mm` geometric dimensions used as rule-drawing input when judging the turning space.
- **Design constraint:** the team abstracts the tightest continuous-turn situation as an internal **375 mm** narrow-corridor constraint, to check the full swept envelope of vehicle, tyres, and safety margin.
- **Scope:** `375 mm` is the team's design and physical-validation constraint, not a single dimension printed on this drawing; passability still depends on the CAD geometry and physical driving results below.

##### Steering geometry and swept-envelope analysis across iterations

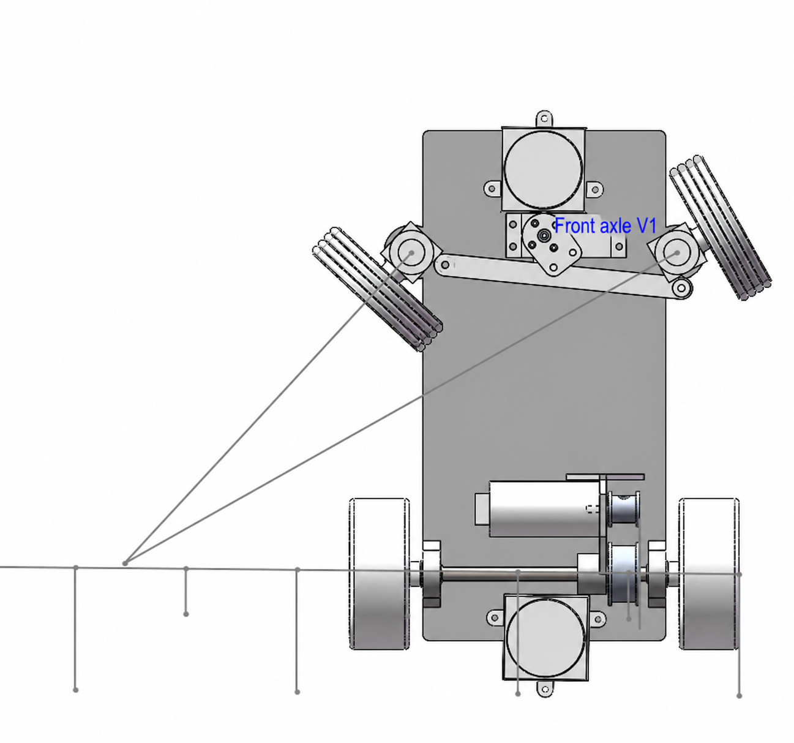
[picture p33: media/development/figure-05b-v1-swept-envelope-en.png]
Initial V1 CAD plan view: front wheels at large steering angle and extended steering axes intersecting at the turn centre.


- **What the drawing records:** V1 axle positions, track, front/rear overhang, large front-wheel angle, and steering axes; their intersection marks the geometric turn centre for this posture.
- **Iteration scope:** V1 is only the starting point. The table compares V1, shortened V2, and the current configuration using the same swept-envelope reasoning.
- **Design check:** the team did not compare theoretical rear-axle radius alone. Passability was assessed from the swept envelope formed by the full vehicle body, outer wheel, and front/rear overhang.
- **Required calculation:** the original required-course-width calculation identifies course dimensions, vehicle-geometry inputs, turn path, and safety clearance; it does not infer a course dimension from this CAD image.

| Version | Geometry and design decision | Evidence and outcome | Decision |
|---|---|---|---|
| V1 | Width 183 mm; length 268 mm; wheelbase 145 mm; front-wheel design angles 58 degrees inside and 30 degrees outside; front overhang 64 mm. The CAD estimate placed the outer wheel approximately 280 mm from the turning centre. | The original design calculation gave a required course width of 561 mm with 30 mm clearance, or 581 mm with 40 mm clearance—both exceeding the team's 375 mm course constraint. This was a geometric analysis, not a physical test. | Rejected as too long for the target turn. The next iteration reduced overall length, wheelbase, and front overhang, and reconsidered rear-tyre friction. [V1 CAD render](https://github.com/clover1983/robot-wro-2026-prepare/blob/main/hardware-info/hardware-design-image/design-001/001.png) |
| V2 | Width 176 mm; length 220 mm; wheelbase 138 mm; front-wheel design angles 53.7 degrees inside and 33.7 degrees outside. | This CAD-stage iteration reduced the swept envelope. CAD renders 017, 018, and 019 record the revised geometry, but V2 was not yet the complete final vehicle assembly. | Intermediate compact-geometry iteration; its selected dimensions were carried into the final V3 package. |
| V3 / current configuration | Final complete vehicle geometry: body length 220 mm; body width 120 mm; overall width including wheels 155 mm; wheelbase 138 mm; rear wheel diameter `65 mm`; front wheel diameter approximately `50 mm`. | V3 made the physical package substantially narrower than V2 and completed the wheels, rear drive, sensor locations, and multi-layer chassis. During running, high-friction commercial rear wheels caused tyre scrub at large steering angles. Arc running became more stable after replacing them with self-made, smoother `65 mm` rear wheels, with the earlier slip no longer observed. | Final V3 configuration: retain the low multi-layer front-steering/rear-drive layout and smoother 65 mm rear wheels. |

- **Final layout principle:** 3D-printed component carriers and multiple standoff-connected levels give every component an intentional mounting position.

Mechanical version history, CAD geometry, swept-envelope analysis, and physical-test records are consolidated in [Chapter 4: Mobility and Mechanical Design](docs/04-mobility-and-mechanical-design.md); this README retains only the final design decisions.

---

## B. Steering and Drive Mechanism

#### Steering geometry selection

- **2025 limitation:** parallel steering did not give sufficiently repeatable tight turns.
- **Reference observation:** the 2026 reference linkage appeared to use reverse Ackermann, where the outer wheel can turn by as much as or more than the inner wheel; this can suit high-speed vehicles with tyre slip-angle and load-transfer effects.
- **Final decision:** positive Ackermann, where the inner wheel turns more sharply than the outer wheel.
- **Reason:** this low-speed vehicle performs tight, repeatable manoeuvres. Positive Ackermann brings the wheel directions closer to their circular paths, reducing tyre scrub and making turns smoother and more repeatable.

##### Steering-geometry comparison

Comparison of the reverse-Ackermann concept observed on the reference platform and the final vehicle's positive-Ackermann concept.

- **Left:** the Reverse-Ackermann relationship observed on the reference platform, in which the outer-wheel angle is at least the inner-wheel angle.
- **Right:** the final vehicle's positive-Ackermann relationship, in which the inner wheel turns farther and the extended front-wheel axes point toward the same turn centre.
- **Scope:** the diagram explains the geometric relationship; its illustrative wheel angles are not presented as unmeasured physical-car data.

#### Front steering and rear drive layout

- **Front axle:** the steering actuator and linkage implement the Ackermann geometry.
- **Rear axle:** one motor, belt transmission, and a supported axle drive both rear wheels.
- **Why not front drive:** driven wheels, motor transmission, and steering joints would have to coexist in the same limited front-axle space.
- **Why this split:** it reduces packaging and linkage complexity, keeps the front steering accessible for adjustment, and leaves the central layers for sensors, controllers, battery, and protected cable routing.
- **Why not four-wheel drive:** a second driven axle was not needed for this vehicle or layout.

#### Low-speed turning with a shared rear axle and no differential

- A shared rear axle keeps both rear wheels at the same angular speed. During a low-speed turn, however, the inside and outside rear wheels follow different paths, so some tyre scrub is unavoidable.
- The earlier `68 mm` commercial rear wheels had coarse tread and high friction. At large steering angles, the team observed occasional slip.
- The team compared adding front ballast, limiting the maximum steering angle, and changing the rear wheels. Front ballast would consume mass budget, while reducing steering angle alone would reduce clearance in tight spaces.
- The final solution was a team-printed **smoother `65 mm` rear wheel**. In arc-driving tests, the vehicle was more stable than with the high-friction wheels and the earlier slip was no longer observed, so no additional front ballast was installed.

| Early commercial treaded rear wheel | Final team-printed smoother rear wheel |
|---|---|
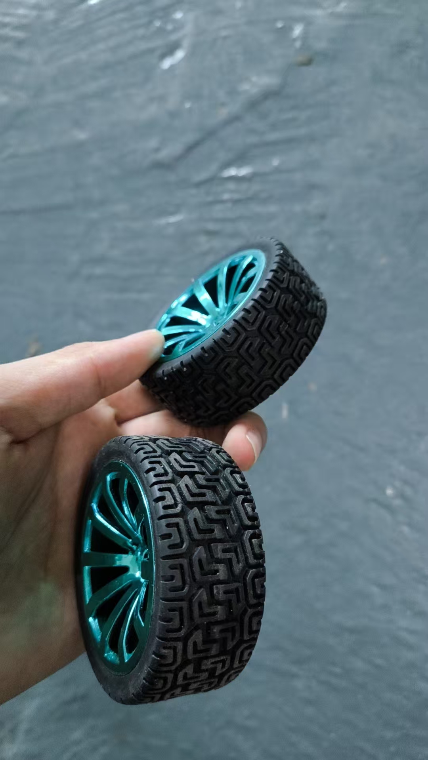
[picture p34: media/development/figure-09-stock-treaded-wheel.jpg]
Early 68 mm commercial treaded tyre.
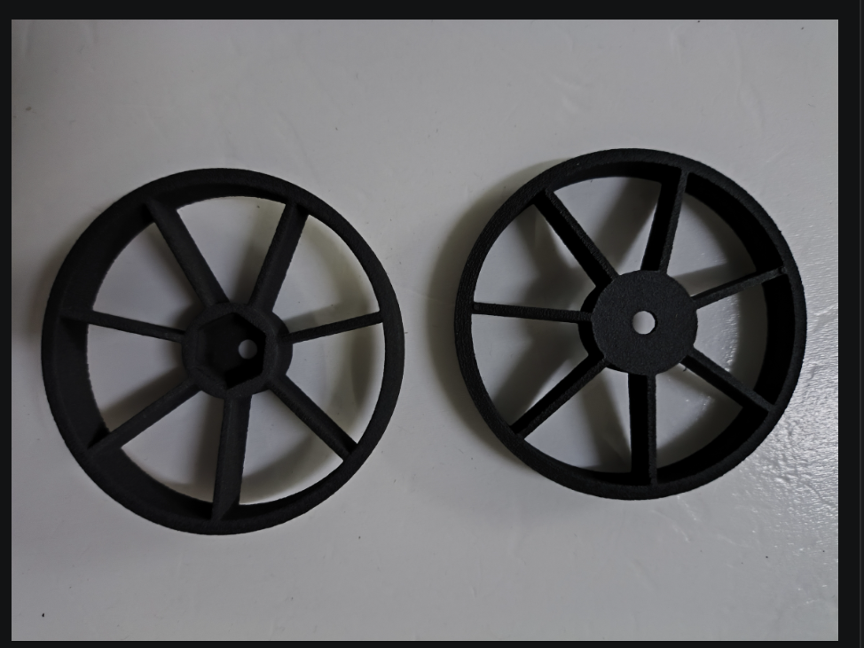
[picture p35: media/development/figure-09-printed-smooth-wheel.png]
Final team-printed smoother 65 mm rear wheel.
|  |  |

- **What the comparison shows:** the left image is the early coarse-tread, high-friction commercial wheel; the right image is the team's final `65 mm` rear-wheel hub. The physical arc-driving result is recorded in the [Chapter 4 testing and iteration record](docs/04-mobility-and-mechanical-design.md).

#### Turning-radius reasoning

For a given maximum steering angle, wheelbase, and ideal kinematic turn, the rear-axle-centre radius is approximately:

$$
R \approx \frac{L}{\tan(\delta)}
$$

- **Kinematic implication:** reducing wheelbase or increasing usable steering angle reduces the theoretical rear-axle-centre radius.
- **Practical check:** evaluate the full swept envelope, not the radius alone.
- **Evidence method:** CAD geometry and the repeated physical-run records in [Chapter 4](docs/04-mobility-and-mechanical-design.md).

##### Final steering mechanism

| Steering assembly before installation | Three-part linkage rod-end detail |
|---|---|
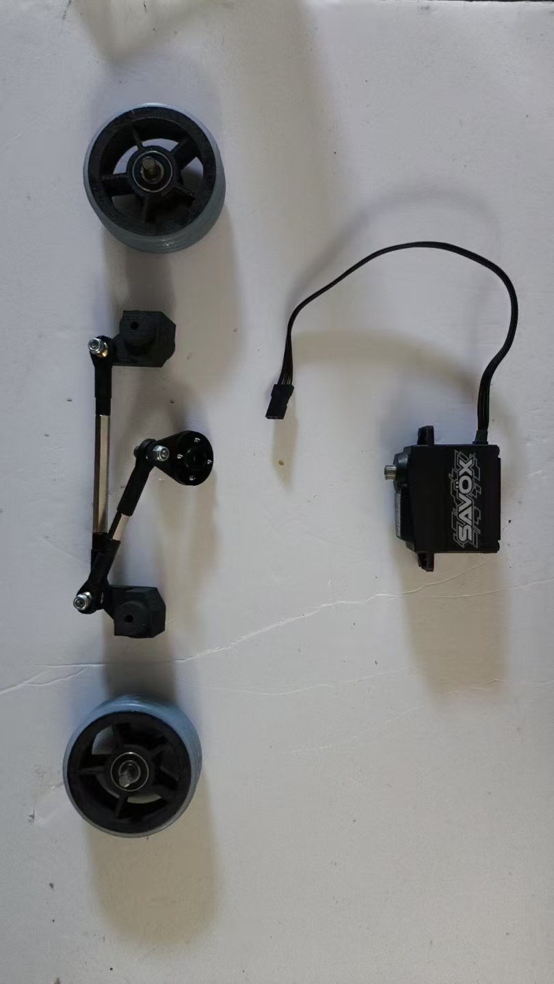
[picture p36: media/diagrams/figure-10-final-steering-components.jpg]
Front steering assembly: both front wheels, steering arms, tie rod, servo horn, and servo.
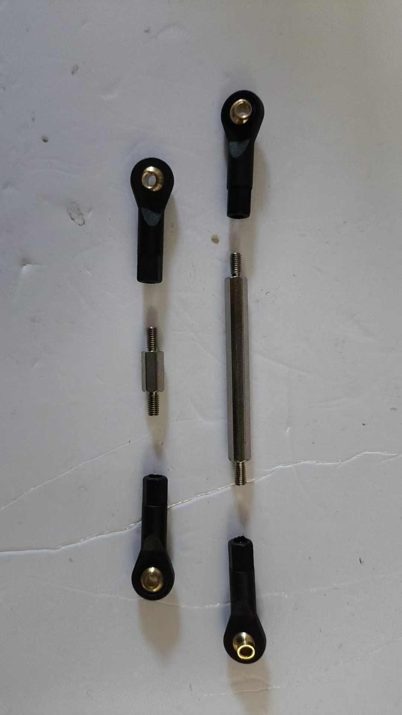
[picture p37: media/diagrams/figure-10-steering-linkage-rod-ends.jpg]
Ball joint and adjustable end of the three-part linkage rod.
|  |  |

- **What the images show:** servo output travels through the servo horn and linkage to the tie rod, which synchronises the two steering arms. Ball joints and adjustable rod ends allow the linkage lengths and centre position to be corrected after assembly.
- **Geometric boundary:** these assembly photographs demonstrate the parts and their connections; the actual inner/outer wheel angles, mechanical stops, and CAD geometry are recorded separately with full-steering photographs and final dimensions.

##### Final rear-drive mechanism

| Rear-drive parts before assembly | Rear-drive CAD relationship |
|---|---|
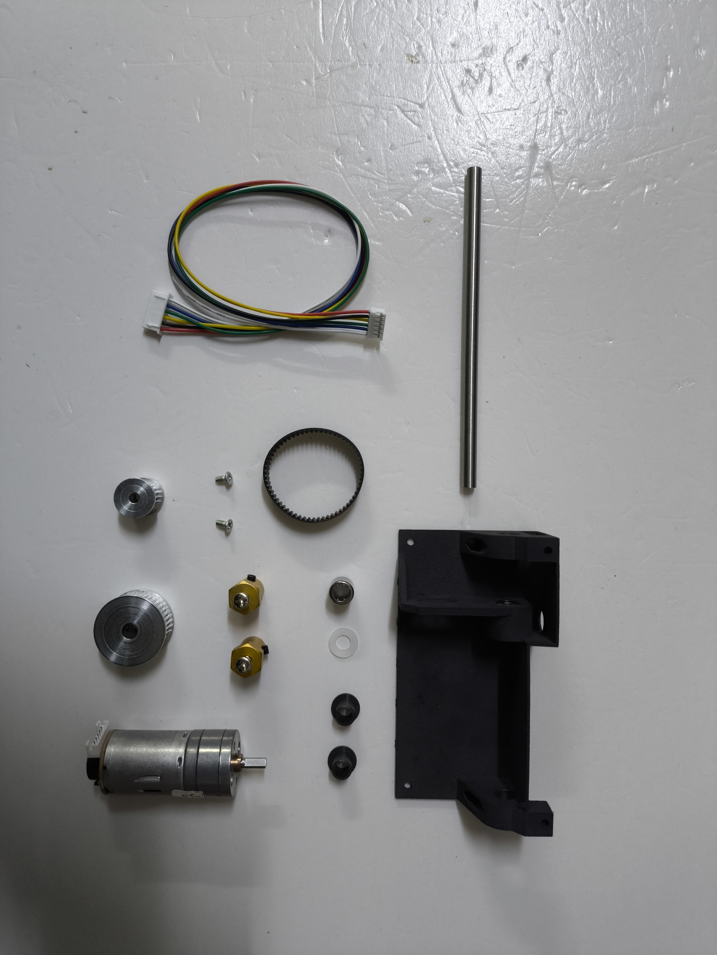
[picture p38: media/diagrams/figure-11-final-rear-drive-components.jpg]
Rear-drive parts: GA25-370 motor, 20T pulley, 40T pulley, timing belt, rear axle, bearings, bearing blocks, and mounting parts.
|  | Rear-drive CAD: the 20T motor pulley drives the 40T rear-axle pulley through the timing belt. |

- **What the images show:** the gearbox-output shaft carries the `20T` pulley, and the timing belt drives the `40T` pulley on the supported rear axle, forming an additional `2:1` reduction that drives both rear wheels through the shared axle.
- **Connection to the calculations:** this transmission ratio is used in the speed and torque calculations in Section C below.

##### Front-axle linkage installation

| Installation view A | Installation view B |
|---|---|
| Front-linkage installation view A: servo, horn, three-part linkage rod, tie rod, and steering arms. | Front-linkage installation view B: the mechanical connection from servo to tie rod viewed from the other side. |

- **What the images show:** the two installation views record the connection between servo output, the three-part linkage rod, the tie rod, and the left/right steering arms.
- **Geometry note:** steering angles and mechanical stops are established by the final CAD dimensions and physical protractor records; they cannot be inferred from these two assembly photographs alone.

---

## C. Torque and Speed Reasoning

**Drive train evaluated:** 12 V GA25-370 gearmotor → 20T-to-40T timing-belt reduction → shared rear axle → 65 mm rear tyres. The reasoning below starts with the rear-wheel traction requirement, then checks motor torque, launch acceleration, race-speed target, and physical-car results.

> [!IMPORTANT]
> **Steering-servo torque and response speed:** [Chapter 4, Section 11: SC-1258TG+ selection](docs/04-mobility-and-mechanical-design.md#11-steering-servo-torque-and-response-speed-selection) — explains how the selected servo provides sufficient steering torque while its faster response supports compact low-speed turns.
>
> **Rear-drive motor torque and selection:** [Chapter 4, Section 12: GA25-370 selection](docs/04-mobility-and-mechanical-design.md#rear-drive-motor-selection) — provides the full traction-force, rear-wheel torque, belt-reduction, tyre-grip, and five-run test calculations.
>
> **Race-time budget and target speed:** [Chapter 4, Section 13: time budget and speed](docs/04-mobility-and-mechanical-design.md#13-run-time-budget-and-rear-drive-target-speed) — provides the full 14 m distance, 100 s driving-time, and rpm conversion calculation.

### 1. Start motor selection from the rear-wheel torque requirement

Rear-drive motor selection starts with the tangential traction force required at the rear wheels, rather than the motor's advertised force rating. With a `32.5 mm` rear-wheel radius, the required axle torque is:

$$
\tau_{\text{rear axle}}=F_{\text{traction}}\times r_{\text{rear wheel}}
$$

Using a `1.45 kg` vehicle, `C_{rr}=0.05`, and a design launch acceleration of `0.5 m/s²`, the rear axle requires approximately `0.0466 N·m`, or `0.48 kgf·cm`. The `0.5 m/s²` value is a design condition for launch capability; the planned `0.14 m/s` average speed is a race-time requirement, so they are different quantities.

### 2. Compare the requirement with the selected GA25-370

At `12 V`, the selected GA25-370 has a rated gearbox-output torque of `0.3 kgf·cm`. After the external `20T:40T` timing-belt reduction and an assumed `90%` transmission efficiency, the rated rear-axle torque is approximately `0.0529 N·m`, or `0.54 kgf·cm`, above the `0.48 kgf·cm` design requirement. The motor and belt drive therefore cover the normal low-speed launch requirement.

### 3. How torque affects acceleration, and the tyre-grip boundary

Motor torque becomes driving force through the rear-wheel radius; after rolling and turning resistance are subtracted, the remaining force produces acceleration. The tyre-static-friction limit also caps the traction that can reach the ground: if the force implied by axle torque is greater than the available static friction, the rear wheels spin instead of producing more acceleration. From the rated rear-axle torque and straight-line rolling resistance, the theoretical straight-line acceleration boundary is about `0.83 m/s²`; the `0.5 m/s²` launch design point retains margin. Lower acceleration is needed in turns, around obstacles, and on lower-grip surfaces.

### 4. Derive the target average speed from the three-minute race

The team reserved `100 s` for obstacle driving, `40 s` for parking, and the remaining `40 s` of the three-minute round for unexpected events. The four sides of the `3 m × 3 m` course total `12 m`; a further `2 m` was included for turning and obstacle-avoidance curves, giving a planned `14 m` route length:

$$
v_{\text{target average}}=\frac{14\ \text{m}}{100\ \text{s}}=0.14\ \text{m/s}
$$

At `0.14 m/s`, a `65 mm` rear wheel turns at approximately `41.1 rpm`; through the `20T:40T` belt drive, this is approximately `82.3 rpm` at the gearbox output, below the motor's `500 rpm` rated gearbox-output speed.

### 5. Straight-line physical-car test and calculation result

The team performed five `0 → 150` straight-line tests on a flat WRO mat using the competition `4500 mAh` battery. `150` is the control command used for this test, not an rpm, m/s, acceleration, or torque unit. The five tests produced a mean steady speed of `0.319176 m/s` and a mean 10%–90% acceleration of `0.545253 m/s²`. That steady speed corresponds to approximately `93.8 rpm` at the rear axle and `187.6 rpm` at the gearbox output, still below the `500 rpm` rated speed. Using the test value `C_{rr}=0.03`, the back-calculated rear-axle requirement is approximately `0.0396 N·m`; the gearbox-output requirement is approximately `0.0220 N·m`, giving a torque margin of about `1.34` against the rated output.

<details>
<summary>Full calculations and five straight-line test records</summary>

### Cruise speed and control-input boundary

- **Time budget:** 100 s for obstacle driving, 40 s for parking, and the remaining part of the three-minute round for recovery from unexpected events.
- **Measured result:** five `0 → 150` straight-line runs on a flat WRO mat with the competition battery produced a mean steady speed of **0.319 m/s**.
- **Firmware range:** motor command 0–400 maps linearly to 13-bit PWM 0–8191.
- **Command 150:** `150 / 400 = 0.375`, or approximately `3071 / 8191` PWM duty.
- **Meaning of the command:** a control input, **not** an rpm, m/s, acceleration, or torque value. The firmware uses direct PWM without a speed controller or acceleration ramp; battery voltage, current limit, load, and tyre grip determine the resulting vehicle motion. See [motor control source](../newcode/202603/esp32-code/motor-api.ino).

**Measured speed calculation at motor command 150**

$$
C = \pi D = \pi \times 0.065 = 0.2042\ \text{m}
$$

$$
n_{\text{rear axle}}
= \frac{v \times 60}{C}
= \frac{0.319176 \times 60}{0.2042}
= 93.78\ \text{rpm}
$$

$$
n_{\text{gearbox output}}
= 93.78 \times \frac{40}{20}
= 187.56\ \text{rpm}
$$

- **Result:** at 0.319 m/s, the 65 mm tyres require approximately **93.78 rpm** at the rear axle and **187.56 rpm** at the GA25-370 gearbox output.
- **Speed comparison:** the selected 9.6:1 motor is specified at **625 rpm maximum no-load gearbox-output speed**, so 187.56 rpm is below that limit.

### Torque requirement and component-selection comparison

- **Vehicle mass:** measured **1.45 kg** with the competition battery.
- **Measured acceleration:** five-run mean 10–90% acceleration of **0.545 m/s²** (sample SD 0.063 m/s²). For each run, the analysis uses the 10% and 90% points of its steady speed from `/wheel/odometry`.
- **Rolling resistance:** `Crr = 0.03`, where `Crr = F_roll / (m × g)`.
- **Selected motor:** 12 V, 9.6:1 version; **625 rpm** maximum no-load gearbox-output speed; **500 rpm** rated speed; and **0.3 kgf·cm** rated gearbox-output torque = **0.0294 N·m**.
- **Torque boundary:** 0.0294 N·m already includes the internal 9.6:1 gearbox, so the calculation does not multiply it by 9.6 again. The 1.2 kgf·cm limit-load torque is not used as a normal operating value.

**Measured acceleration and torque calculation**

$$
F_{\text{acc}}
= m a
= 1.45 \times 0.545253
= 0.791\ \text{N}
$$

$$
F_{\text{roll}}
= C_{rr}mg
= 0.03 \times 1.45 \times 9.81
= 0.427\ \text{N}
$$

$$
F_{\text{required}}
= F_{\text{acc}} + F_{\text{roll}}
= 1.217\ \text{N}
$$

$$
T_{\text{rear axle}}
= F_{\text{required}}r
= 1.217 \times 0.0325
= 0.0396\ \text{N\,m}
$$

$$
T_{\text{gearbox, required}}
= \frac{T_{\text{rear axle}}}{2 \times 0.90}
= 0.0220\ \text{N\,m}
$$

$$
T_{\text{gearbox, rated}}
= 0.3\ \text{kgf\,cm} \times 0.09807
= 0.0294\ \text{N\,m}
$$

$$
\text{Rated torque margin}
= \frac{0.0294}{0.0220}
= 1.34
$$

$$
T_{\text{rear axle, rated}}
= 0.0294 \times 2 \times 0.90
= 0.0529\ \text{N\,m}
$$

- **Required gearbox-output torque:** **0.0220 N·m**.
- **Manufacturer-rated gearbox-output torque:** **0.0294 N·m**.
- **Rated-torque margin:** **1.34**.
- **Rear-axle comparison:** with the 2:1 belt reduction and `η = 0.90`, the requirement is 0.0396 N·m and theoretical rated torque is 0.0529 N·m.

### Straight-line acceleration evidence

- **Test date and surface:** 2026-08-21; flat WRO mat; competition battery.
- **Initial condition:** vehicle at rest, steering command 0, and a direct motor-command step from 0 to 150.
- **Measurement source:** `/wheel/odometry` provided timestamp, speed (`twist.twist.linear.x`), and path distance.
- **Stop condition:** stop command sent after measured path reached at least 1 m.

| Run | Motion-onset delay (s) | 10–90% acceleration (m/s²) | Steady speed (m/s) | Command to 1 m (s) |
|---:|---:|---:|---:|---:|
| 1 | 0.098 | 0.507 | 0.319 | 3.395 |
| 2 | 0.094 | 0.533 | 0.319 | 3.390 |
| 3 | 0.087 | 0.643 | 0.319 | 3.392 |
| 4 | 0.081 | 0.479 | 0.319 | 3.404 |
| 5 | 1.362 | 0.565 | 0.319 | 4.697 |

- **10–90% acceleration result:** mean **0.545 m/s²**.
- **Secondary analysis:** linear fit over the same rise interval gives **0.460 m/s²** (sample SD 0.089 m/s²); the torque calculation uses the higher 10–90% value.
- **Distance result:** from motion onset, the vehicle reached 1 m in **3.311 s** on average (sample SD 0.017 s).
- **Run 5:** longer motion-onset delay, while acceleration and steady speed remained comparable to the other runs.
- **Evidence files:** [wro_acceleration_runs.zip](../wro_acceleration_runs.zip) contains raw bags, CSV files, JSON analysis, and the test report; [torque-speed-calculations.csv](hardware/mechanical/calculations/torque-speed-calculations.csv) is the editable calculation record.

</details>

---

## D. Mechanical Stability and Rigidity

**Design objective:** preserve the relative positions of the steering, rear-drive, LiDAR, and electronics modules during repeated driving and turning.

- **From PLA prototype to carbon-fibre-filled nylon.** The first structural layers were PLA because it was quick to print and suitable for validating component packaging, layer relationships, and assembly order. PLA was not sufficiently rigid or durable as the long-term material for repeated servo-steering loads, rear-drive transmission loads, and fastener-hole loads. The team therefore moved to carbon-fibre-filled nylon rather than treating the early PLA prototype as the final load-bearing structure.

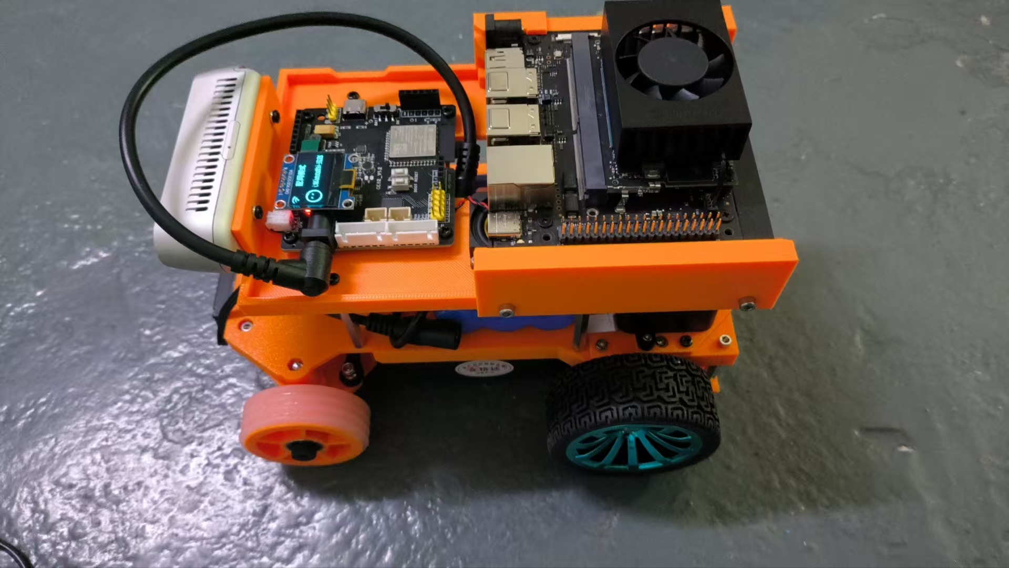
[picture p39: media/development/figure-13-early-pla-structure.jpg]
Early vehicle assembled with PLA structural layers.
  

- **PA12-CF versus PA6-CF.** PA12-CF has lower moisture sensitivity and better dimensional stability. PA6-CF better fits the higher-rigidity demand of this vehicle's lower layers: the front-axle servo steering, rear timing-belt drive, and repeatedly assembled mounting holes all depend on stable geometry. Within the `1.5 kg` mass limit, added metal reinforcement was not a suitable alternative, so the lowest and second layers use **PA6-CF**.

- **The insulated electronics layer remains PLA.** The team tested the resistance of the carbon-fibre-filled print material; the probe reading shown below demonstrates that it cannot be treated as an insulator. The upper layer carries the ESP32-S3, Jetson, and other electronics, so it was changed to PLA. This deliberately prioritises electrical insulation over maximum structural rigidity.

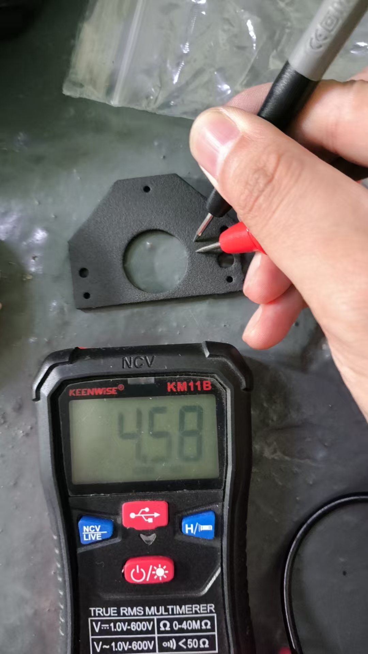
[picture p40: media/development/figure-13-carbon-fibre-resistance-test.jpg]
Resistance test of a carbon-fibre-filled print: multimeter probes touch the printed part and show a measurable resistance reading.
  

- **Multi-layer frame and interlocking second layer.** Brass double-ended hex standoffs connect the printed levels and limit relative movement between them. The second level is not one unsupported flat plate: it uses nested, recessed printed sections with defined openings for the battery bay, cable routes, and sensor mounts. The interlocking joints keep the assembled surface flush while reinforcing the edges around those openings.

  Final multi-layer CAD assembly, showing the modular layout of the lower, middle, and upper levels.

- **Fixed mechanical interfaces and protected harnesses.** Printed mounting features locate the servo, motor, rear-axle supports, battery, LiDARs, and cable routes. Stable locations reduce the risk of gear misalignment, steering backlash, sensor movement, and cable forces acting on the steering or drive assemblies. The harness is routed inside the vehicle perimeter rather than used as an exposed load-bearing element.

  Fixed internal cable route and protected space around the rear wheel.

- **LiDAR mounting stability.** Both 2D LiDARs are mechanically mounted below 95 mm so their scan planes intersect the approximately 100 mm-high walls and obstacles. The rear LiDAR is mounted 5 mm higher and is longitudinally offset from the front LiDAR, so the sensors do not share exactly the same scan plane or direct line of exposure. Rigid printed mounts preserve this geometry during driving.

  Final vehicle front view: the front depth camera and low-mounted sensor area are fixed within the multi-layer chassis.

---

## E. Design Trade-offs, Component Selection, and Iteration

This table does not repeat the complete technical explanation in Sections A–D. It is a development index: each row links the progression of a structure, sensor, or power decision described above.

| Period | Constraint or problem found | Team adjustment | Result and final decision |
|---|---|---|---|
| 2025-10: V1 chassis | The `268 mm` long V1 with a `145 mm` wheelbase had too large a full swept envelope for the `375 mm` narrow-space constraint. | Shortened the body and wheelbase, then reorganised the front axle, rear axle, LiDAR, and battery space. | Established the `220 mm`-long, `138 mm`-wheelbase V2 geometric basis. See [A. Chassis Design Choices](#a-chassis-design-choices). |
| 2025-10: LiDAR scan plane | Inverted LiDAR mounting was considered to simplify wiring; the centrally inverted LiDAR in the previous vehicle produced unreliable returns. | Reserved sensor positions and cable paths from the chassis-design stage; kept the scan height below the approximately `100 mm` course walls and obstacles. | Retained low mounting for two 2D LiDARs; their longitudinal positions are offset and the rear mount is `5 mm` higher. |
| 2025-10 to 11: battery | A two-battery layout adds mass and cable complexity and does not fit the competition's single main-switch startup rule. | Moved to one 12 V main battery and one main power switch; rejected the magnetic battery-mount concept. | Retained a low, screw-secured single-battery bay. See [power budget and one-battery architecture](#a-power-budget-one-battery-architecture-and-evidence). |
| 2025-11 to 12: rear wheels | A shared rear axle with high-friction `68 mm` commercial wheels produced tyre scrub and occasional slip at large steering angles. | Tested team-printed smoother `65 mm` rear wheels. | Arc driving became more stable and the earlier slip was not observed; retained the smoother `65 mm` wheels without adding front ballast. |
| 2025-11 to 12: structural material | PLA prototypes were useful for rapid validation but unsuitable for long-term structural loads near the front axle, rear axle, and timing-belt drive. | Compared PA12-CF, PA6-CF, and metal reinforcement; selected PA6-CF for the lower layers. | Retained PA6-CF for the load-bearing lower levels. |
| 2025-12: electronics-layer material | Carbon-fibre-filled material is conductive and should not contact controller circuit boards. | Changed the top layer that carries the ESP32-S3, Jetson, and electronic interfaces to PLA. | Retained the PLA top layer, accepting lower structural rigidity in exchange for electrical insulation. |
| 2025-11 to 12: Jetson–ESP32 communication | USB serial was unstable and Wi-Fi was unsuitable as the competition's primary connection. | Selected the ESP32-compatible W5500 wired interface and designed a dedicated mounting location for the Ethernet module, port orientation, and right-angle Ethernet lead. | Retained the W5500 wired link and protected Ethernet routing. |
| 2025-11 to 12: power and harness | Two controllers, sensors, and actuators share limited space; wrong connector specifications or leads that are too short create installation and power failures. | Standardised connectors to the DC5521 that was physically verified to conduct; checked polarity and power before soldering; adjusted the lengths of motor, Ethernet, and sensor leads. | All harnesses remain inside the vehicle perimeter, with room for maintenance and reconnection. |

> [!IMPORTANT]
> **Detailed engineering document:** [Mobility and Mechanical Design](docs/04-mobility-and-mechanical-design.md) — chassis, steering, rear drive, wheels, materials, cable management, and mechanical iteration.

---

# 2. Power & Sensor Architecture

This is a map of the final electrical and sensing decisions. It gives the design conclusion and the evidence route; component-level specifications, photographs, circuit references, and the complete reasoning are collected in [Power and Sensor Architecture](docs/05-power-and-sensor-architecture.md).

## A. Power budget, one-battery architecture, and evidence

- **One protected power source:** a `12 V / 4.5 Ah` WHEELTEC battery feeds both controllers through one competition main-power switch: a DC5525 branch supplies the Jetson and a DC5521 branch supplies the ESP32 driver board. The component total is `27.12 W / 2.26 A` during operation; the short-duration wire-sizing value, including margin, is `7.6 A`.
- **A deliberate voltage decision:** the team considered a `12 V → 19 V` Jetson boost converter, but retained direct 12 V input after reference review and vehicle testing because the converter would add mass.
- **Harness and operating protection:** the installed main lead is `14 AWG` and both controller branches are `18 AWG`; the battery bay is screw-secured, the power wiring is enclosed within the vehicle, and the OLED battery monitor flashes blue below `9%`. The main switch disconnects the vehicle; the program-start button remains a separate software-start control.
- **Evidence:** [component power and current table](hardware/electronics/power-budget.csv) · [power topology, cable construction, battery comparison, and safety measures](docs/05-power-and-sensor-architecture.md#component-power-and-current-assessment)

## B. Sensor and communication trade-offs

| Device or link | Final role | Reason for the selection or connection |
|---|---|---|
| Two STL-27L 2D LiDARs | Front-and-rear horizontal obstacle and wall ranging | A pair of lightweight planar scanners provides the distance layer used for avoidance; their scans are merged to improve front/rear coverage. |
| RealSense D435f | Forward red/green obstacle recognition with depth information | It replaces the earlier fisheye approach with a repeatable forward mount and depth data; its recognition result is combined with LiDAR distance rather than used alone. |
| TM171 IMU and Hall encoder | Vehicle attitude/yaw input and wheel-pulse odometry | The IMU supports vehicle-state interpretation, while the encoder is the wheel-feedback source used by the vehicle odometry. |
| W5500 wired Ethernet | Jetson–ESP32 micro-ROS transport | It replaces the less reliable USB serial path and avoids relying on Wi-Fi as the competition communication link. |

The complete interface paths, power rails, cable choices, photographs, and datasheets are in [Chapter 05: sensor, cable, and interface record](docs/05-power-and-sensor-architecture.md#sensor-cable-and-interface-record).

## C. Placement proved against the field geometry

The `100 mm` walls, traffic signs, and parking limits set the installation reference. Because the vehicle depends primarily on LiDAR for avoidance, both scan planes are installed at approximately `85 mm`, so they intersect these field objects instead of passing above them. The front LiDAR is oriented at `0°`; the rear LiDAR is inverted by `180°` to simplify scan fusion. This priority has a visible trade-off: the D435f is mounted above `100 mm`, which can remove a very close obstacle from its non-fisheye view. [The geometry assessment and installation rationale are recorded in Chapter 05](docs/05-power-and-sensor-architecture.md#assessment-of-field-geometry-and-sensor-installation-positions).

## D. Calibration and common vehicle frame

The team first completed each ROS 2 sensor's intrinsic-calibration and configuration procedure using the vendor packages. For the shared vehicle frame, it measured installed component offsets with callipers, encoded positions and orientations in URDF/Xacro, and checked the resulting model in Gazebo against the CAD-exported STL layout. This establishes the transforms for both LiDARs, the D435f, and the IMU without presenting an unsupported automatic camera–2D-LiDAR calibration result. [Calibration trials, rejected tools, and the final frame method](docs/05-power-and-sensor-architecture.md#sensor-calibration-and-extrinsic-frame-construction).

## E. Failure points and reliability iterations

- **LiDAR wiring:** an initial `30 cm` ZH1.5-4P-to-USB-A lead did not make the LiDAR respond. The final front and rear paths use `20 cm` ZHR-4-to-2.54 mm Dupont leads; the rear path additionally uses a `5.5 cm` CP2102 TTL-to-USB adapter because the available GPIO UART interfaces were insufficient.
- **Coverage and camera risk:** brass standoffs can leave local gaps after dual-LiDAR merging. The team also made `15°` and `20°` camera-mount variants to improve close-range lower view, but did not install them because they would require new camera extrinsics.
- **Thermal and installation revisions:** the Jetson-support clearance was increased from `30 mm` to `40 mm` to improve IMU ventilation, and the later support revision added the program-start button. The IMU was rotated by `180°` to keep its cable inside the vehicle; the tested steering behaviour remained correct.
- **Protected assembly:** cable routing, connector selection, battery retention, and the hand-soldered split harness were treated as reliability work rather than incidental assembly.

Each issue includes the physical evidence and final decision in [Chapter 05: failure points and iterations](docs/05-power-and-sensor-architecture.md#failure-point-measured-coverage-risks-and-an-unused-camera-mount-iteration).

> [!IMPORTANT]
> **Detailed engineering document:** [Power and Sensor Architecture](docs/05-power-and-sensor-architecture.md) — power budget, source evidence, device interfaces, geometry, calibration, failure points, and iterations.

---

# 3. Software Architecture & Obstacle Strategy

## Software modules and runtime chain

The Jetson ROS 2 planner is the decision centre of the final system; the ESP32-S3 controls the motor, servo, OLED, audio, and encoder interfaces. The Jetson exchanges control and status topics with the ESP32 through W5500 wired Ethernet and the micro-ROS Agent. Two LiDARs, the D435f, the IMU, and the encoder form the closed-loop inputs. There is no separate final controller written only for Open Challenge: the same `Driver` and `GridPlanner` select fewer or more task branches according to whether an active obstacle is present.

| Module | Actual responsibility | Main inputs | Outputs and protection |
| --- | --- | --- | --- |
| Sensor and wall-line processing | Separate dual-LiDAR scans into wall lines, obstacle candidates, and local occupancy. | Merged LiDAR scan and sensor timestamps. | `LocalGrid` plus wall/obstacle evidence. |
| Pose and direction determination | Maintain continuous pose from encoder odometry and IMU; use LiDAR walls only for limited correction and course-direction confirmation. | Odometry, IMU, and wall lines. | Vehicle pose and direction-lock state. |
| Mapping and path planning | Fuse local observations into `GlobalGrid`; perform weighted path search from route goals, walls, vehicle footprint, and clearance. | LocalGrid, pose, known obstacles, and corner goals. | A feasible look-ahead path and behavioural plan. |
| Recognition and arbitration | Associate D435f red/green observations with LiDAR obstacle distance; select priority behaviour among obstacles, corners, and normal route following. | Camera colour observations, LiDAR tracks, and planner state. | Passing side, wait, reverse, or normal-route plan. |
| Driver and safety layer | Map geometric look-ahead to the servo and route speed to the motor, while checking data freshness and short-horizon collision prediction. | Path, LiDAR, IMU, and odometry. | Motor/servo commands; zero commands when scan, IMU, or odometry is invalid. |

## Two challenge branches of the shared planner

```mermaid
flowchart LR
  A[LiDAR / IMU / encoder / D435f] --> B[Freshness check and pose update]
  B --> C[Fuse LocalGrid into GlobalGrid]
  C --> D{Active obstacle?}
  D -->|No: Open Challenge| E[Corridor guidance, route goals, corners, and laps]
  D -->|Yes: Obstacle Challenge| F[Colour association, passing side, weighted path, and recovery]
  E --> G[Geometric look-ahead and motion prediction]
  F --> G
  G --> H[ESP32 motor and servo]
  H --> A
```

**Open Challenge** produces no obstacle plan in a course without red/green pillars. It still identifies direction from LiDAR openings and wall lines, maintains a corridor route, passes four corners, and stops only after a confirmed third lap. The early “wall line + approximately `0.40 m` centring target + odometry distance + IMU `+90°`” baseline validated the obstacle-free course; the final version has been absorbed into the shared grid planner. [Complete Open Challenge strategy](docs/07-open-challenge-strategy.md)

**Obstacle Challenge** adds red/green recognition, LiDAR–camera association, obstacle-priority arbitration, weighted clearance paths, and a safe reverse for an uncoloured nearby obstacle to that same chain. It is not a prerecorded route: wall lines, local/global grids, and new obstacle observations continually affect the next action. [Complete Obstacle Challenge strategy, algorithm rationale, and metrics](docs/08-obstacle-challenge-strategy.md)

Parking is a competition task, but the parking-area detector, parking state machine, and physical-vehicle validation were not completed this season. The current planner stops at three-lap completion rather than inserting an unvalidated parking action into final autonomous running. [Parking scope statement](docs/09-parking-strategy.md)

## Safety and edge cases

| Situation | Current handling | Design reason |
| --- | --- | --- |
| LiDAR, IMU, or odometry is stale or absent | The Driver zeros motor and servo commands. | Do not keep moving without data used for localisation or collision avoidance. |
| Direction evidence is insufficient | Retain unknown direction and use corridor guidance; direction lock requires consecutive frames and a score difference. | Avoid generating an entire lap in the wrong direction from one ambiguous wall scan. |
| LiDAR sees a nearby obstacle but the camera has no reliable colour | Wait briefly for colour; if it remains unknown, select a safe reversing distance and sense/plan again. | Do not treat an unclassified nearby obstacle as free space. |
| Weighted search cannot supply a safe path | Stop or wait for a new observation instead of driving on unconditionally. | Walls, obstacles, and vehicle clearance jointly limit routes. |
| Corner-entry or exit deviation | Use corner states, IMU heading, odometry, wall margin, and `corner-backup` when needed. | A corner is a recoverable process, not one large servo command. |
| Motion continues after three laps | `course_complete` zeros the actuator outputs. | Avoid repeated start-line counting and driving beyond the finish. |

> [!IMPORTANT]
> **Detailed engineering documents:** [Software Architecture and decisions](docs/06-software-and-control-architecture.md) · [Open Challenge](docs/07-open-challenge-strategy.md) · [Obstacle Challenge](docs/08-obstacle-challenge-strategy.md) · [Parking scope statement](docs/09-parking-strategy.md)

---

# 4. Systems Thinking & Engineering Decisions

The vehicle is treated as one coupled system: a mechanical change alters sensing geometry, a power choice changes mass and wiring, and a software architecture has to fit the physical course and the available sensors. The following record turns the main decisions in Chapters 01–05 into traceable constraint–option–evidence–consequence chains.

## Decision record

| ID | Constraint and alternatives | Decision and evidence | System consequence and verification |
|---|---|---|---|
| D-01 — steering and vehicle envelope | The vehicle must turn in the `375 mm` course space without a differential drive. Parallel steering previously required repeated corrections; reverse Ackermann favours high-speed cornering rather than this vehicle's low-speed turns. | **Positive Ackermann and the V3 geometry** were selected over parallel/reverse Ackermann. V1 required `561–581 mm` of turn width in the recorded calculation; V3 uses a `220 mm` body and `138 mm` wheelbase, with a theoretical rear-axle-centre radius of about `154.1 mm`. | The inner front wheel turns more than the outer wheel, reducing low-speed scrub. The planner version completes most ordinary corners in one continuous pass; full swept-envelope validation remains a separate physical check. [Mechanical decision and test record](docs/04-mobility-and-mechanical-design.md#tests-and-results) |
| D-02 — shared rear axle and wheel material | The rules prohibit differential-wheeled drive, but a shared rear axle creates tyre drag at large steering angles. High-friction `68 mm` commercial wheels produced drag and occasional slip. | **Smoother `65 mm` 3D-printed rear wheels** were selected instead of the high-friction commercial wheels. Arc-driving comparison showed more stable motion and less observed drag/slip. | This does not eliminate the physical limitation of a non-differential axle; positive Ackermann and the wheel choice reduce it. [Rear-wheel trade-off](docs/04-mobility-and-mechanical-design.md#4-tyre-drag-trade-off-for-the-shared-rear-axle-without-a-differential) |
| D-03 — range sensing, mass, and field geometry | Walls, signs, and parking limits are `100 mm` high. A 3D LiDAR would simplify camera–LiDAR calibration but the lightest candidate was about `210 g`; two 2D LiDARs weigh about `90 g` together. | **Two 2D LiDARs** were selected instead of one 3D LiDAR. Their scan planes are approximately `85 mm`, below `95 mm`, so they intersect the `100 mm` course objects; the front unit is `0°` and the rear unit `180°` for scan merging. | The combined `/scan` improves front/rear coverage within the mass limit. It remains planar data: brass standoffs can occlude parts of the scan, and the high D435f can lose very-close obstacles from view. [Geometry, calibration, and known coverage limits](docs/05-power-and-sensor-architecture.md#assessment-of-field-geometry-and-sensor-installation-positions) |
| D-04 — controller and communication architecture | Perception and planning need SBC resources, actuator timing needs an SBM, Wi-Fi is not permitted, and the ESP32 has no suitable driver for the USB-Ethernet candidate. `micro_ros_espidf_component` also conflicted with the board's ESP-IDF 5.4 environment. | **Jetson + ESP32-S3 over W5500 wired Ethernet**, with `micro_ros_arduino`, was selected instead of one controller, Wi-Fi, USB Ethernet, or the conflicting ESP-IDF deployment. | Jetson runs ROS 2 perception/decision work; ESP32 runs actuator and encoder functions. W5500 and the protected cable route provide the physical bridge; the micro-ROS deployment was completed on the selected board. [Architecture decision record](docs/03-system-architecture.md#jetson-esp32-and-wired-communication) · [SBM selection](docs/05-power-and-sensor-architecture.md#why-esp32-s3-was-selected-as-the-sbm) |
| D-05 — power source, voltage, and harness | Competition allows one power-on operation, while two batteries, a boost module, and extra wiring add mass and failure points. | **One `12 V / 4.5 Ah` battery with direct Jetson DC5525 input** was selected instead of the early dual-battery arrangement and the `12 V → 19 V` boost module. The component assessment gives `27.12 W / 2.26 A` operating load and a `7.6 A` short-duration wire-sizing value; the vehicle program ran stably in most cases on direct 12 V. | The final harness uses a `14 AWG` main lead and two `18 AWG` branches, with a separately switched Jetson and ESP32 supply path. Battery enclosure, screw retention, internal routing, main switch, and low-battery indication reduce handling and wiring risk. [Power evidence and safety measures](docs/05-power-and-sensor-architecture.md#component-power-and-current-assessment) |
| D-06 — localization and planning approach | Generic SLAM and navigation packages must operate in a `375 mm` corridor with small obstacles and noisy onboard state inputs. | **A team-built map, localization, and planner chain** was selected instead of `slam_toolbox`, RTAB-Map, Nav2, and the `robot_localization` EKF output. The SLAM maps jumped, RTAB-Map was less stable, Nav2 inflation did not fit the course, and the EKF output was too noisy. | The final chain uses merged LiDAR scan, depth camera, IMU, and encoder information; wheel odometry is calculated from encoder pulses. This makes the current limitations explicit rather than hiding them behind an unstable generic stack. [Software trade-off](docs/03-system-architecture.md#software-architecture-trade-off) · [IMU/odometry decision](docs/05-power-and-sensor-architecture.md#sensor-calibration-and-extrinsic-frame-construction) |

## Active risks and mitigations

| Risk or failure mode | Mitigation now used | Remaining check or limitation |
|---|---|---|
| Local LiDAR blank returns and near-field camera loss | Merge two LiDAR scans, retain previous observations in state management, and use LiDAR distance alongside camera recognition. | Brass standoffs still create physical occlusion; the `15°` and `20°` downward-camera-mount variants were not adopted because they require new camera extrinsics. |
| Cable, connector, or wheel contact | Route every power, sensor, Ethernet, motor, and servo lead through internal printed-layer openings; use verified connectors and inspect the harness before use. | The inverted-LiDAR cable and camera USB connection are startup inspection items; no cable may hang outside the vehicle outline. |
| Heat, material deformation, or transmission failure | Raised the Jetson/IMU support from `30 mm` to `40 mm`; use PA6-CF in lower structural layers, PLA at the electronics layer, and metal timing pulleys at the critical drive position. | The upper PLA electronics layer has a slight bend without affecting operation; post-run inspection remains necessary. |
| Program-start and micro-ROS communication interruptions | The program-start service ignores repeated presses after the planner has started; timeout and watchdog handling reduce Agent restarts. | Button-release handling and occasional Agent restart remain open software limitations. |

The complete evidence path is [team process and scope](docs/01-team-and-project.md), [requirements and rules](docs/02-requirements-and-constraints.md), [system architecture and software trade-offs](docs/03-system-architecture.md), [mechanical calculations and tests](docs/04-mobility-and-mechanical-design.md), and [power, interfaces, calibration, and sensor risks](docs/05-power-and-sensor-architecture.md).

> [!IMPORTANT]
> **Detailed engineering documents:** [Requirements and Constraints](docs/02-requirements-and-constraints.md) · [Testing and Iteration](docs/10-testing-and-iteration.md) · [Risks and Failure Modes](docs/11-risks-and-failure-modes.md)

---

# 5. Reproducibility & GitHub Quality

## Reproduction path

Use the following linked route to reproduce the documented vehicle. The links deliberately lead to the physical records, drawings, photographs, interface assignments, and setup notes rather than to a generic checklist.

| Step | Action and evidence to use |
|---|---|
| 1 | **Identify and obtain the parts.** Start with the [sensor, cable, interface, and datasheet record](docs/05-power-and-sensor-architecture.md#sensor-cable-and-interface-record), the [fastener and structural-hardware inventory](docs/12-build-and-operation-guide.md#fasteners-and-structural-hardware), and the [component power assessment](docs/05-power-and-sensor-architecture.md#component-power-and-current-assessment). These records identify the installed devices, interface paths, cable lengths, power rails, supplier/datasheet evidence, and recorded fasteners. |
| 2 | **Make or obtain the mechanical parts.** Use the dimensioned [mechanical drawing (PDF)](media/cad/botzill-autonomous-ackerman-car-drawing.pdf), the editable [mechanical assembly model (STEP)](media/cad/Botzill%20Autonomous%20Car%20-%20Hiway%20Mechanical%20Assembly.step.zip), and the CAD/STL links in [Chapter 4 evidence](docs/04-mobility-and-mechanical-design.md#evidence-links). |
| 3 | **Rebuild the chassis in physical order.** Follow [Mechanical Reconstruction](docs/12-build-and-operation-guide.md#mechanical-reconstruction), using the [108-photo assembly manifest](media/assembly-steps/complete-sequence/assembly-step-manifest.csv) and the [complete photo archive](media/assembly-steps/complete-sequence/). The steps cover the lower chassis, battery bay, LiDAR layer, cable passages, upper electronics layer, and final inspection. |
| 4 | **Install and check steering and rear drive.** Use the front-Ackermann and rear-belt assembly operations in [Mechanical Reconstruction](docs/12-build-and-operation-guide.md#mechanical-reconstruction), supported by the [front-axle/servo and rear-drive assembly photos](media/assembly-guide/README.md). Confirm free steering travel, pulley alignment, belt tension, wheel fit, and that no cable enters a moving mechanism. |
| 5 | **Wire controllers, sensors, and actuators.** Follow the carrier-board interface assignments in [Chapter 05](docs/05-power-and-sensor-architecture.md#jetson-orin-nano-super-developer-kit-carrier-board-power-and-interfaces-used-on-this-vehicle), the [LiDAR connection guide](media/assembly-guide/lidar-connection/lidar-how-to-connect.md), and the [W5500-to-ESP32 guide](media/assembly-guide/w5500-esp32-connection/w5500-how-to-connect-esp32.md). These cover the final LiDAR harnesses, rear CP2102 converter, USB devices, 40-pin-header pins, W5500 leads, and the two DC power branches. |
| 6 | **Perform electrical safety checks before controller connection.** Check polarity, continuity, flag-terminal/switch joints, protected cable routing, and the 12 V/5 V/3.3 V domains against the [power tree](docs/05-power-and-sensor-architecture.md#final-power-tree-and-voltage-domains) and [electrical and wiring safety measures](docs/05-power-and-sensor-architecture.md#electrical-and-wiring-safety-measures). |
| 7 | **Install the Jetson, ROS 2, serial, Ethernet, and sensor dependencies.** Use [System Installation and Initialisation](docs/12-build-and-operation-guide.md#system-installation-and-initialisation) for the current route, then the [detailed installation-record index](docs/12-installation-record/README.md) for screenshot-level Jetson, ROS 2, LiDAR, camera, IMU, Ethernet, and dependency procedures. |
| 8 | **Flash the ESP32 firmware and start the micro-ROS Agent.** Follow the detailed [Arduino/ESP32 procedure](docs/12-installation-record/005-Arduino-01.md) and [micro-ROS Agent procedure](docs/12-installation-record/006-microROSAgent-Jetson.md); confirm the controller topics and start-button behaviour in the pre-run checks of [Chapter 12](docs/12-build-and-operation-guide.md#6-initialisation-and-pre-run-checks). |
| 9 | **Set deployment-specific parameters.** Detect serial devices and configure the W5500 Ethernet interface as described in [serial and Ethernet access](docs/12-build-and-operation-guide.md#3-enable-serial-and-ethernet-access). Then use the documented ROS 2 topics, frames, and data flows in [Chapter 3](docs/03-system-architecture.md#physical-connections-ros-2-topics-and-data-flows). Keep usernames, hostnames, passwords, and private network credentials out of committed files. |
| 10 | **Establish sensor and vehicle calibration.** Reproduce the measured URDF/Xacro coordinate-frame method in [Sensor Calibration and Extrinsic-Frame Construction](docs/05-power-and-sensor-architecture.md#sensor-calibration-and-extrinsic-frame-construction), then verify steering travel and rear-drive operation through the mechanical checks in [Chapter 4](docs/04-mobility-and-mechanical-design.md#tests-and-results). |
| 11 | **Run layered verification.** Start with [sensor tests](tests/sensor-tests/README.md), [mechanical tests](tests/mechanical-tests/README.md), and [software tests](tests/software-tests/README.md); then run the complete [Open Challenge](tests/open-challenge/README.md), [Obstacle Challenge](tests/obstacle-challenge/README.md), and [regression checks](tests/regression-tests/README.md). |

### Detailed linked documents

- **Mechanical parts and dimensions**
  - [Fasteners and structural hardware](docs/12-build-and-operation-guide.md#fasteners-and-structural-hardware)
  - [Dimensioned mechanical drawing (PDF)](media/cad/botzill-autonomous-ackerman-car-drawing.pdf)
  - [Mechanical assembly model (STEP)](media/cad/Botzill%20Autonomous%20Car%20-%20Hiway%20Mechanical%20Assembly.step.zip)
  - [CAD, drawing, and STL evidence index](docs/04-mobility-and-mechanical-design.md#evidence-links)

- **Physical assembly**
  - [Current lower-to-upper reconstruction sequence](docs/12-build-and-operation-guide.md#mechanical-reconstruction)
  - [English assembly-photo manifest](media/assembly-steps/complete-sequence/assembly-step-manifest.csv)
  - [Complete sequential assembly-photo archive](media/assembly-steps/complete-sequence/)
  - [Curated front axle, rear drive, LiDAR, cable, W5500, and start-button photographs](media/assembly-guide/README.md)

- **Power, electronics, and wiring**
  - [ESP32 driver-board rails and interfaces used](docs/05-power-and-sensor-architecture.md#esp32-driver-board-power-and-interfaces-used-on-this-vehicle)
  - [Jetson carrier-board power and interfaces used](docs/05-power-and-sensor-architecture.md#jetson-orin-nano-super-developer-kit-carrier-board-power-and-interfaces-used-on-this-vehicle)
  - [Final power tree and voltage domains](docs/05-power-and-sensor-architecture.md#final-power-tree-and-voltage-domains)
  - [LiDAR harness and CP2102 connection guide](media/assembly-guide/lidar-connection/lidar-how-to-connect.md)
  - [W5500-to-ESP32 connection guide](media/assembly-guide/w5500-esp32-connection/w5500-how-to-connect-esp32.md)

- **Jetson, ROS 2, and ESP32 deployment**
  - [Jetson initial setup](docs/12-installation-record/001-jetson.md)
  - [ROS 2 installation](docs/12-installation-record/002-ros2.md)
  - [Ethernet, kernel modules, and user groups](docs/12-installation-record/008-add-module-config-eth-user-group.md)
  - [LiDAR installation and validation](docs/12-installation-record/009-LiDAR.md)
  - [Camera SDK installation](docs/12-installation-record/011-Camera-SDKs.md)
  - [TM171 IMU installation](docs/12-installation-record/014-imu.md)
  - [Arduino IDE and ESP32 firmware upload](docs/12-installation-record/005-Arduino-01.md)
  - [micro-ROS Agent on Jetson](docs/12-installation-record/006-microROSAgent-Jetson.md)

- **Calibration and verification**
  - [Intrinsic calibration, manual URDF/Xacro extrinsics, and coordinate frames](docs/05-power-and-sensor-architecture.md#sensor-calibration-and-extrinsic-frame-construction)
  - [Sensor tests](tests/sensor-tests/README.md) · [mechanical tests](tests/mechanical-tests/README.md) · [software tests](tests/software-tests/README.md)
  - [Open Challenge test record](tests/open-challenge/README.md) · [Obstacle Challenge test record](tests/obstacle-challenge/README.md) · [regression checks](tests/regression-tests/README.md)

> [!IMPORTANT]
> **Detailed engineering document:** [Build and Operation Guide](docs/12-build-and-operation-guide.md)

---

## Repository navigation

| Folder | Contents |
|---|---|
| `docs/` | Engineering-journal chapters and rubric evidence map |
| `hardware/` | BOM, mechanical calculations, CAD, wiring, pinouts, and power budget |
| `software/` | Code organized by module, configuration, setup, and tests |
| `tests/` | Test plans, raw results, analysis, and regression evidence |
| `media/` | Required team and robot photos, development evidence, diagrams, and video links |
| `releases/` | Competition baselines and release notes |

---

## Quick links

- [Engineering Journal index](docs/00-engineering-journal.md)
- [Rubric Evidence Map](docs/13-rubric-evidence-map.md)
- [AI Use and Authorship](docs/14-ai-use-and-authorship.md)
- [Build and Operation Guide](docs/12-build-and-operation-guide.md)
- [Official rules reference](rules/README.md)

---

## Software quick start

```bash
colcon build
source install/setup.bash
ros2 launch robot planner.launch.py
```

`planner.launch.py` starts its prerequisite processes and then `wro_planner`; launch arguments control whether simulation, micro-ROS, autonomous driving, and the debug view are connected. [Planner launch file](https://github.com/AGitUser0001/WRO-FE-2026/blob/main/src/robot/launch/planner.launch.py) [Runtime parameter definitions](https://github.com/AGitUser0001/WRO-FE-2026/blob/main/src/robot/planner/config.py)

---

## Evidence and traceability

The [Rubric Evidence Map](docs/13-rubric-evidence-map.md) points judges to the primary and supporting evidence for each criterion. Test records preserve raw measurements and do not replace failed results with only successful trials.

---

## Demonstration videos

- [Open Challenge video](https://youtu.be/FDlq30FkXkA?si=35xpGzAMFtRC2q4T)
- [Obstacle Challenge video](https://youtu.be/ZCeJy3AIbls?si=Dyjuz9C3nUB4ehGs)
- [Technical explanation video](media/videos/video-links.md)

---

## Current status

- Hardware version: `V3`
- Software version: `v1.0`

---

## License

This repository is licensed under the [Apache License 2.0](LICENSE).

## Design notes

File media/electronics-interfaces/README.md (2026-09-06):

# Electronics interfaces

Physical evidence of vehicle electronics interfaces used by the system-architecture documentation.

- `tm171-imu-installation-highlighted.png`: TM171 IMU location inside the vehicle.
- `imu-usb-c-interface-closeup.jpeg`: close-up of the IMU USB-C interface.
- `imu-usb-c-to-jetson-usb-a-overview.jpeg`: wider view of the IMU-to-Jetson USB connection.
- `imu-usb-c-port.jpeg`: IMU USB-C port.
- `lidar-2-usb-dupont-cable.jpeg`: LiDAR 2 cable detail.
- `front-lidar-zhr4-interface.jpeg` and `front-lidar-zhr4-to-gpio-dupont.jpeg`: front-LiDAR ZHR-4 interface and its Dupont-jumper connection to Jetson GPIO.
- `rear-lidar-zhr4-interface.jpeg`, `rear-lidar-zhr4-cp2102-rx-to-usb-a.jpeg`, and `cp2102-usb-a-rx-interface.jpeg`: rear-LiDAR ZHR-4 interface and its CP2102-to-Jetson USB-A connection.
- `w5500-to-esp32-dupont-jumpers.jpeg`: close-up of W5500-to-ESP32 Dupont jumpers.
- `w5500-integrated-wiring-01.jpeg` and `w5500-integrated-wiring-02.jpeg`: broader W5500 wiring views.
- `w5500-jetson-ethernet-esp32-dupont-overview.jpeg`: W5500 Ethernet and Dupont-jumper overview.

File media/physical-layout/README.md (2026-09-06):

# Physical layout

Physical photographs used to document the vehicle's layered layout in the system-architecture chapter.

- `layer-01-bottom-chassis.jpg`: lowest chassis layer.
- `layer-02-lidar.jpg`: middle LiDAR layer.
- `layer-03-top-deck.jpg`: top deck before the upper electronics are installed.
- `layered-rear-view.jpg`: rear view of the layered vehicle.
- `top-layer-esp32-speaker.jpg`: upper layer with ESP32 and speaker.
- `layered-vehicle-with-jetson.jpg`: complete layered vehicle after Jetson installation.
- `upper-layer-cable-routing.jpeg`: upper electronics and completed cable routing.

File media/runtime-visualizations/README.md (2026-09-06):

# Runtime visualizations

This folder stores screenshots and recordings from runtime tools such as RViz. These files are evidence of live sensor, transform, merge, control, or telemetry behavior; they are not CAD renders, vehicle photographs, or illustrative diagrams.

Use descriptive filenames in the form `<subsystem>-<view-or-output>-rviz.png` when applicable. Each image used in the engineering journal must have a caption that states what was displayed and what claim the image supports.

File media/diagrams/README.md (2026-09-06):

# Diagrams

Place exported architecture, flow, and state diagrams in this folder. Replace this note with an index of the final files.

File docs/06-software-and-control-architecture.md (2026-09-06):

# Software and Control Architecture

## Summary

The robot did not begin with the final dedicated planner. Development first used the standard ROS 2 ecosystem: Ubuntu, ROS 2, sensor drivers, Gazebo, `robot_localization`, SLAM Toolbox, RTAB-Map, and Nav2 ran on the Jetson; the ESP32-S3 acted through micro-ROS as the real-time endpoint for motor, steering, encoder, display, and audio functions. After repeated simulator and physical-vehicle evaluation, the team retained ROS 2 for messages, drivers, visualisation, and build tools, but replaced SLAM/Nav2 as the competition-time navigation method with a dedicated state machine built around the known field, LiDAR, IMU, encoder odometry, and team-developed mapping and path-planning logic.

This was not a departure from ROS 2. ROS 2 remains the communication and driver foundation; the final control workspace is built with `colcon build` and launched with `ros2 launch`.

## Initial architecture and technical direction

The first software architecture deliberately centred on the ROS 2 ecosystem: sensor topics would feed perception, localisation, SLAM, Nav2, and actuator control, while the Jetson would command the ESP32 through the network.

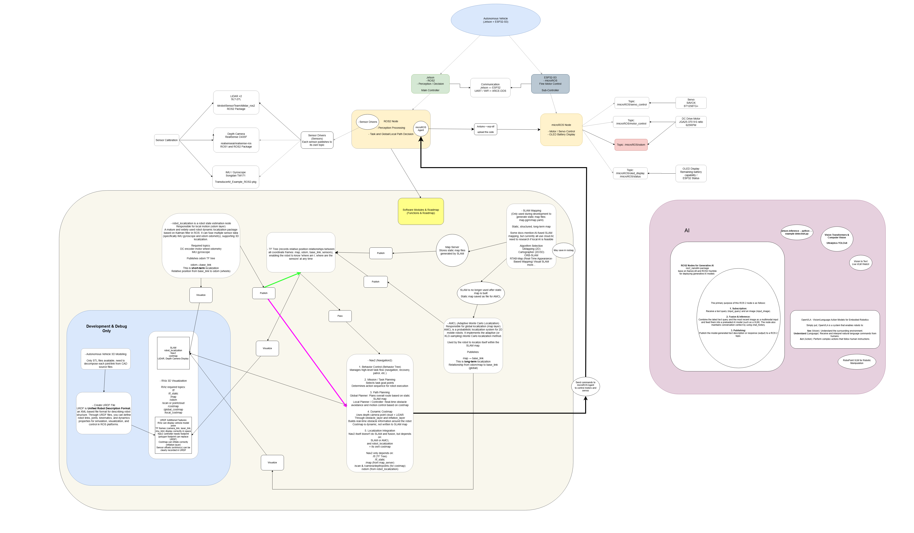
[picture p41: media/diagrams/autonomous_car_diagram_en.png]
Initial autonomous-car software architecture.


The early brainstorming map records the same intent: reuse common ROS libraries and begin with SLAM, Nav2, sensor fusion, and simulator tools rather than writing a dedicated navigator at the outset.

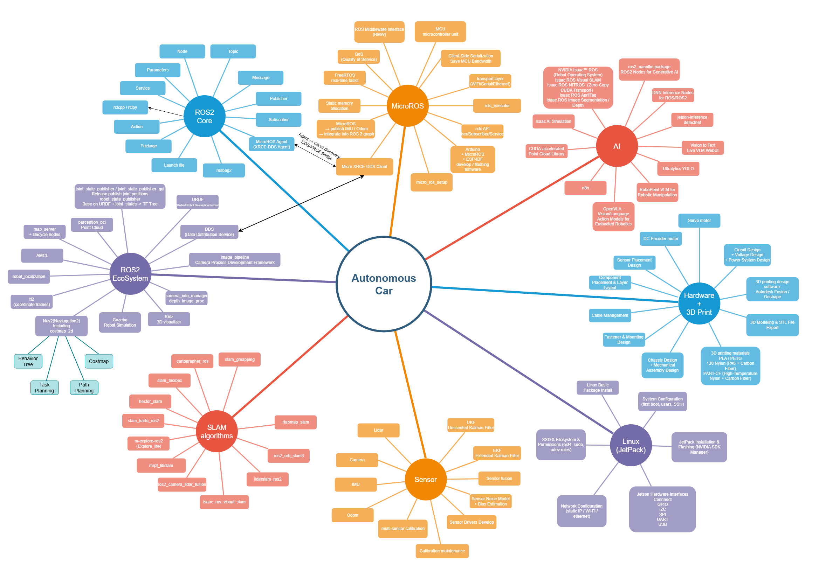
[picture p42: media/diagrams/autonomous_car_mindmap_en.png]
Early software-development mind map.


The benefit was reusable interfaces for drivers, transforms, recording, visualisation, and navigation. The corresponding risk was that general-purpose navigation components still had to remain stable on this small field, around short-range obstacles, and with this vehicle's sensor noise. The later iterations were driven by that risk.

## Platform, operating system, and ROS 2 baseline

The team selected JetPack 6.1 / Ubuntu 22.04 for the Jetson Orin Nano Super Developer Kit and ROS 2 Humble, which matches Ubuntu 22.04. Humble is a long-term-support release; for this project, stability, available driver support, and compatibility with the Jetson system took priority over a newer ROS release.

The initial system setup, ROS 2 installation, base dependencies, and USB-device detection are retained as reproducible records:

| Work | Record |
|---|---|
| Flash JetPack, first boot, and system update | [001 — Jetson system](12-installation-record/001-jetson.md) |
| Install ROS 2 Humble and check talker/listener | [002 — ROS 2](12-installation-record/002-ros2.md) |
| Build and device dependencies; Python check | [003 — Base dependencies](12-installation-record/003-base-dependency.md) |
| ESP32-S3 USB detection, serial device, and user-group permissions | [004 — ESP32-S3 USB detection](12-installation-record/004-esp32s3-usb-detect.md) |

These steps initially used an HDMI monitor, keyboard, and mouse. The team subsequently configured [VNC remote access](12-installation-record/010-VNC.md), allowing development and debugging without continuously attaching HDMI.

## ESP32 and micro-ROS: a clear toolchain iteration

The ESP32-S3 does not make high-level path decisions. It serves as the single-board microcontroller (SBM) for the low-level motor, steering, encoder, display, and audio functions. From the beginning, the team planned to use micro-ROS so ROS 2 nodes on the Jetson could exchange topics and commands with the ESP32.

### Not adopted: `micro_ros_espidf_component`

The first implementation attempted `micro_ros_espidf_component`. It was not adopted for two reasons:

1. The purchased ESP32 carrier-board code used ESP-IDF 5.4, whereas the attempted micro-ROS component environment depended on ESP-IDF 4.0. The version and dependency conflicts were extensive; downgrading would disrupt the existing carrier-board firmware environment.
2. The team then tried to establish a separate ESP-IDF 4.0 environment, but the available toolchain target at that time was `amd64`; the development MacBook and Jetson are ARM systems and could not directly run or build that environment. Maintaining two incompatible ESP-IDF environments was not suitable for competition development.

The team stopped this route after about one day of investigation.

### Final choice: `micro_ros_arduino`

The team changed to `micro_ros_arduino`. The first alternative implementation successfully flashed the ESP32-S3 and exchanged ROS 2 messages. The Arduino IDE, ESP32 board package, micro-ROS library, and flashing process are recorded in [005 — Arduino and micro-ROS on Jetson](12-installation-record/005-Arduino-Jetson.md). The physical ESP32 firmware is maintained in [src/esp32](https://github.com/AGitUser0001/WRO-FE-2026/tree/main/src/esp32).

The Jetson then ran a micro-ROS Agent, validating the Jetson-to-ESP32 command path and status topics; the build and UDP-Agent sequence is recorded in [006 — Jetson micro-ROS Agent](12-installation-record/006-microROSAgent-Jetson.md). W5500 provides wired Ethernet between the ESP32 and Jetson; the module, addressing, and user-group configuration are documented in [008 — W5500 network configuration](12-installation-record/008-add-module-config-eth-user-group.md).

## Sensors, frames, and runtime data foundation

The following devices entered ROS 2 as topics for both the generic SLAM/Nav2 experiments and the later dedicated control code:

| Module | Runtime role | Installation or configuration record |
|---|---|---|
| Front/rear STL-27L LiDARs and dual-LiDAR merge | Walls, openings, obstacles, and local scans | [009 — LiDAR and dual-LiDAR merge](12-installation-record/009-LiDAR.md) |
| RealSense D435f | Depth/colour images and obstacle-colour information | [011 — RealSense SDK and ROS 2](12-installation-record/011-Camera-SDKs.md) |
| TM171 IMU | Heading and angular velocity; interpreted with wheel odometry | [014 — TM171 IMU](12-installation-record/014-imu.md) |
| GA25-370 encoder | Pulse counts and wheel-odometry basis | [Chapter 5: sensor, cable, and interface record](05-power-and-sensor-architecture.md#sensor-cable-and-interface-record) |

The team also tried software LiDAR–camera extrinsic calibration. Available ROS 2 projects targeted 3D LiDAR, or supported ROS 1 only; an unsuccessful automatic calibration was not presented as the final result. The final extrinsics were established by caliper measurements, URDF/Xacro, and Gazebo comparison against the CAD/STL layout; the detailed method is in [Chapter 5, “Sensor Calibration and Extrinsic-Frame Construction”](05-power-and-sensor-architecture.md#sensor-calibration-and-extrinsic-frame-construction). The manual transforms were accepted when the component-inclusive URDF model overlaid the complete CAD/STL component layout in Gazebo. This work took approximately one month.

## Gazebo, SLAM, and Nav2 evaluation

The team built a Gazebo field world and first tested the vehicle in simulation. The following files are configuration snapshots actually used in that evaluation and now copied into this documentation directory:

| Component | Documentation copy | Purpose |
|---|---|---|
| Gazebo world | [wro-fe-obstacle-textures.world](../media/software-artifacts/ros2-stack-evaluation/wro-fe-obstacle-textures.world) | Field textures, walls, and obstacle scene |
| `robot_localization` EKF | [ekf-odom-imu.yaml](../media/software-artifacts/ros2-stack-evaluation/ekf-odom-imu.yaml) | Trial state estimation from wheel odometry and IMU |
| SLAM Toolbox | [slam-toolbox-online-async.yaml](../media/software-artifacts/ros2-stack-evaluation/slam-toolbox-online-async.yaml) | Online 2D SLAM parameters |
| Nav2 | [nav2-parameters.yaml](../media/software-artifacts/ros2-stack-evaluation/nav2-parameters.yaml) | Costmap, planning, and recovery parameters |

The RTAB-Map 3D-SLAM attempt repeatedly reported that it could not close the loop. SLAM Toolbox did not issue the same loop-closure error, so the team continued mapping experiments with it. SLAM mapping could remain stable during manual driving; however, the map still jumped when Nav2 changed pose. The team repeatedly inspected `robot_localization`: it changed the combinations of IMU and odometry state permitted into the EKF, and even tried IMU alone, but the estimated state remained too noisy and unstable. The final vehicle therefore does not use the EKF output and instead uses team-developed encoder odometry.

The work also encountered these physical issues and limits:

| Problem | Investigation and iteration | Outcome |
|---|---|---|
| ESP32 reset during longer runs | Communication/control timeout increased from about 2 s toward 15 s and a watchdog was added; the values were adjusted several times | Resets became much less frequent, allowing continued vehicle tests. |
| ESP32 crash after extended odometry calculation | The ESP32 no longer completed all odometry calculation; a separate UDP port received encoder pulses and the Jetson calculated odometry | Offloading the computation improved odometry runtime. |
| Nav2 simulator avoidance quickly became infeasible | Costmap, inflation, and avoidance behaviour were checked at the approximately 25 cm scale; the team suspected a mismatch between generic parameter scale and vehicle clearance | No stable obstacle-avoidance behaviour suitable for competition was obtained. |
| SLAM map jump when Nav2 changed pose | SLAM Toolbox, EKF, IMU/odom combinations, and Nav2 were repeatedly adjusted | No closed-loop baseline stable enough for competition was produced. |

After roughly one month of SLAM and Nav2 adjustment without an acceptable competition baseline, the team stopped using the generic SLAM/Nav2 stack as the final autonomous navigator. This was an engineering decision for this field and vehicle, not a claim that the packages are unsuitable in every environment.

## From generic navigation to a dedicated state machine

### Open Challenge: first successful map-free baseline

The team first wrote a dedicated Python controller for the Open Challenge. It obtains the merged LiDAR scan; because the installed scanners have a slight angular offset, the program combines wall-line evidence from the scan with the straight-track assumption and drives along the corridor centre line. Centring is not map optimisation: it is a track-specific hard-coded rule. When LiDAR identifies a wall line on one side, the control target is an offset of approximately `0.4 m` from that wall toward the inside of the course, which approximates the corridor centre. Encoder odometry records travel distance; on the approximately 3 m track, at about 0.55 m before the target area, the program enters a corner state and uses an IMU heading change of approximately `+90°` to complete the turn.

This version had no SLAM or global map. It relied on current wall lines, travelled distance, and predefined corner transitions. Although simple, the first Open Challenge baseline worked quickly, demonstrating that a dedicated state machine could be more reliable than the unstabilised generic navigation chain on the known obstacle-free field.

### Obstacle Challenge: why the Open state machine could not simply be reused

Applying the Open logic directly to the Obstacle Challenge failed because corner and obstacle logic competed for control priority. If corner logic wins, the vehicle can collide with an obstacle; if obstacle logic wins, it can miss a corner, making lap counting and later position decisions incorrect.

Instead of adding temporary priority rules, the team implemented its own map, localisation, and planner for the Obstacle Challenge. Local scans form a local grid, while time-consistent observations update a global grid. Encoder odometry and IMU provide the continuous localisation basis, with finite correction from LiDAR wall/opening features. The planner considers known obstacles, walls, vehicle clearance, corners, and recovery motions within one path-selection chain, allowing obstacle passing, corner handling, safe backup, and replanning to coexist.

The final competition software is maintained in [WRO-FE-2026 `src/robot`](https://github.com/AGitUser0001/WRO-FE-2026/tree/main/src/robot). After cloning, build the workspace with `colcon build`, then run the `ros2 launch` command specified by the selected challenge configuration. Before deployment, complete the Jetson, Agent, network, and sensor checks in [Chapter 12, System Installation and Initialisation](12-build-and-operation-guide.md#system-installation-and-initialisation).

## Final-architecture boundary

The final code still uses ROS 2 for sensor drivers, topic transport, logging, visualisation, building, and launch. micro-ROS remains the real-time control connection between Jetson and ESP32. What was removed from competition-time decision-making was the direct global-localisation or navigation role of RTAB-Map, SLAM Toolbox, `robot_localization` EKF, and Nav2. The retained simulator world and configuration snapshots make the attempts reproducible; the final state machine is designed for the real field's dimensions, repeated geometry, three-lap logic, and safe recovery.

## Evidence and reproduction entry points

- [Initial autonomous-car architecture diagram](../../diagrams/autonomous_car_diagram_en.png)
- [Early development mind map](../../mindmaps/autonomous_car_mindmap_en.png)
- [Complete installation-record directory](12-installation-record/README.md)
- [Gazebo, EKF, SLAM Toolbox, and Nav2 configuration copies](../media/software-artifacts/ros2-stack-evaluation/)
- [ESP32 micro-ROS firmware](https://github.com/AGitUser0001/WRO-FE-2026/tree/main/src/esp32)
- [Final Jetson robot-control code](https://github.com/AGitUser0001/WRO-FE-2026/tree/main/src/robot)

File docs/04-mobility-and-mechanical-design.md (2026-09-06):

# Mobility and Mechanical Design

## Purpose

Record how the team progressively made and iterated decisions about the chassis, steering, drive, wheels, body materials, and mechanical performance so that the vehicle suits the known WRO game map, makes stable non-high-speed turns, and avoids obstacles.

## Summary

The final vehicle uses a three-layer, fully 3D-printed chassis. The lower layer contains the front axle (a front SC-1258TG+ servo drives a positive-Ackermann front axle through a servo-linkage assembly), battery bay, and rear axle (one GA25-370 Hall-encoder gearmotor drives a shared rear axle through a `20T:40T` timing-belt reduction). The body is `220 mm` long, `120 mm` wide, and `158 mm` high; the overall width including wheels is approximately `155 mm`, the vehicle mass is `1.45 kg`, and the wheelbase is `138 mm`. Front-wheel diameter is approximately `50 mm`, rear-wheel diameter is `65 mm`, and chassis ground clearance is `7 mm`. The lowest and second layers use PA6-CF to withstand loads from the servo, rear-drive transmission, and repeated assembly; the upper electronics layer uses PLA so boards do not directly contact conductive carbon-fibre-filled material.

## Design inputs, constraints, and decisions

The table gives an overview of each mechanical design problem. The following subsections retain the decision process, calculations, and specific structural consequences.

| Design problem | Final mechanical decision |
|---|---|
| One continuous `90°` turn | Reject parallel steering and reverse-Ackermann reference layouts; use a positive-Ackermann front axle. |
| Passing the narrowest approximately `375 mm` area | Evaluate body length, width, wheelbase, overhangs, and the outer front-corner swept envelope together, rather than theoretical turning radius alone. |
| Mechanical division between front Ackermann steering and rear drive | The front axle steers only and the rear axle drives only, avoiding the need to route drive torque through a steering front axle and keeping the servo-linkage and rear timing-belt transmissions simple. |
| Rules 11.5 and 11.13: electronic differential prohibition and drive-motor-to-axle connection | Use one GA25-370 drive motor and a shared rear axle without a differential; the `20T:40T` timing belt indirectly connects the motor to and drives both rear wheels. |
| The vehicle has no suspension or rear-axle differential; its front wheels are slightly light, and large steering angles occasionally cause slip | Use smoother, `65 mm` 3D-printed rear wheels without an external silicone covering instead of high-friction commercial rear wheels. |
| Exposed cables on the previous-year vehicle could be dragged into and contact obstacles | Treat cable management as a chassis-design input: determine cable length, connector direction, cross-layer openings, and fixed routes from each component's installed position; keep all cables within the body outline and away from the front axle, rear wheels, timing belt, and other moving parts. |
| Competition rule: one switch may start the complete vehicle; after power-on it must wait for one start button, located on the SBC/SBM or installed separately | Abandon two-battery power and use one `12 V` battery for both SBC and SBM. A `12 V → 19 V` boost module for a higher Jetson input voltage was considered, but rejected because it added mass and tests showed the existing program did not need it. The battery sits in the low bay between the axles, giving a stable centre of gravity and providing mounting and routing for the upper SBC, SBM, and other modules. |
| `100 mm` walls, traffic signs, and parking limits | To keep both 2D LiDAR scan planes below `95 mm` and intersect these objects, the LiDAR-carrying chassis had to be lower; chassis ground clearance was therefore reduced from `20 mm` to `7 mm`. |
| Rule 11.2: complete vehicle mass must not exceed `1.5 kg`; one 3D LiDAR is approximately `210 g`, with no remaining mass budget to accommodate it | To obtain more complete `360°` horizontal-scan coverage around the vehicle, use two 2D LiDARs totalling approximately `90 g` and a ROS 2 merge node instead of the 3D LiDAR approach; offset the front and rear units and raise the rear unit by `5 mm`. |
| Rules 11.2, 11.4, 11.18, and 11.19: `1.5 kg` maximum mass, no caster wheels, and unrestricted materials and manufacturing methods | The listed electronics, actuators, and two battery entries total `871.49 g`. This is not a sensors-and-computing-only figure and excludes the chassis, wheels, transmission, wiring, and fasteners, so the chassis still needs to be fully 3D printed for low mass. The lower two load-bearing layers use PA6-CF and the upper layer touching SBC/SBM hardware uses PLA. |
| The previous year's plastic transmission gear between the motor and bearing failed five times and replacement parts eventually became unavailable | Replace this critical motor-to-rear-axle transmission position with metal gear/pulley components instead of relying on a failure-prone plastic gear. |
| Select between steering-servo torque and response speed | SC-1258TG+ has lower rated torque than the early SC-1256TG candidate, but the two units have the same dimensions and mass. The vehicle uses `4.8 V` supply, so it selects SC-1258TG+ at `9.6 kgf·cm / 0.10 s/60°` to provide the Ackermann front axle with sufficient steering force while shortening steering response time. |
| Evaluate required torque for rear-drive motor selection | Using the `1.45 kg` vehicle mass, `65 mm` driven rear wheels, and low-speed acceleration requirement as inputs, calculate rear-axle torque from the `32.5 mm` rear-wheel radius and convert it to gearbox output through the `20T:40T` timing belt; this supports selecting the GA25-370, whose rated torque covers normal low-speed acceleration. |
| Time budget within the three-minute run: approximately `12 m` of basic course length plus `2 m` reserved for turns, avoidance, and curved travel; plan to cover approximately `14 m` in `100 s` | The target mean speed of `0.14 m/s` corresponds to approximately `41.1 rpm` at the rear axle and `82.3 rpm` at the gearbox output; the measured steady speed of `0.319176 m/s` corresponds to approximately `93.8 rpm` at the rear axle and `187.6 rpm` at the gearbox output. Both are below the GA25-370 rated gearbox-output speed of `500 rpm`. |

### 1. Selecting the steering mode for one continuous `90°` turn

The team first ruled out parallel steering. Although the previous-year vehicle was small, it still needed multiple forward-and-reverse adjustments to turn in the parking area. Its front wheels were small, its available steering angle was limited, and it could easily contact the parking limits or walls in the narrow space. This showed that a small body alone does not guarantee a one-pass turn: front-wheel angle and steering geometry are also decisive.

This vehicle therefore needs a larger inner-wheel angle to make a continuous `90°` turn. The team considered Anti-Ackermann / Reverse-Ackermann geometry, but that arrangement addresses tyre slip angle and load transfer in high-speed vehicles. This WRO vehicle instead follows a known map at non-high speed and prioritises stable turns. The final solution is positive Ackermann: the inner front wheel turns farther than the outer front wheel, bringing the two wheels closer to their respective circular paths.

| Previous-year vehicle with parallel steering: front | Previous-year vehicle with parallel steering: side |
|---|---|
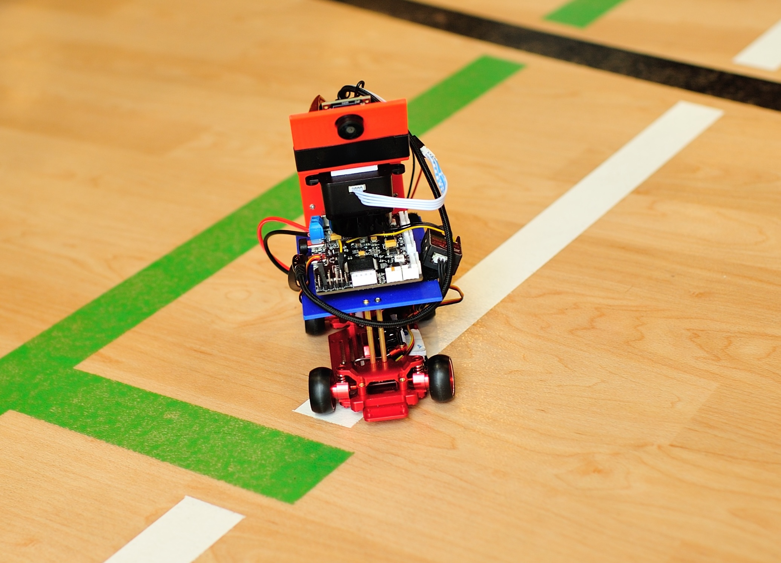
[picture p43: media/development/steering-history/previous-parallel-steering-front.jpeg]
Front view of the previous-year vehicle with parallel steering.
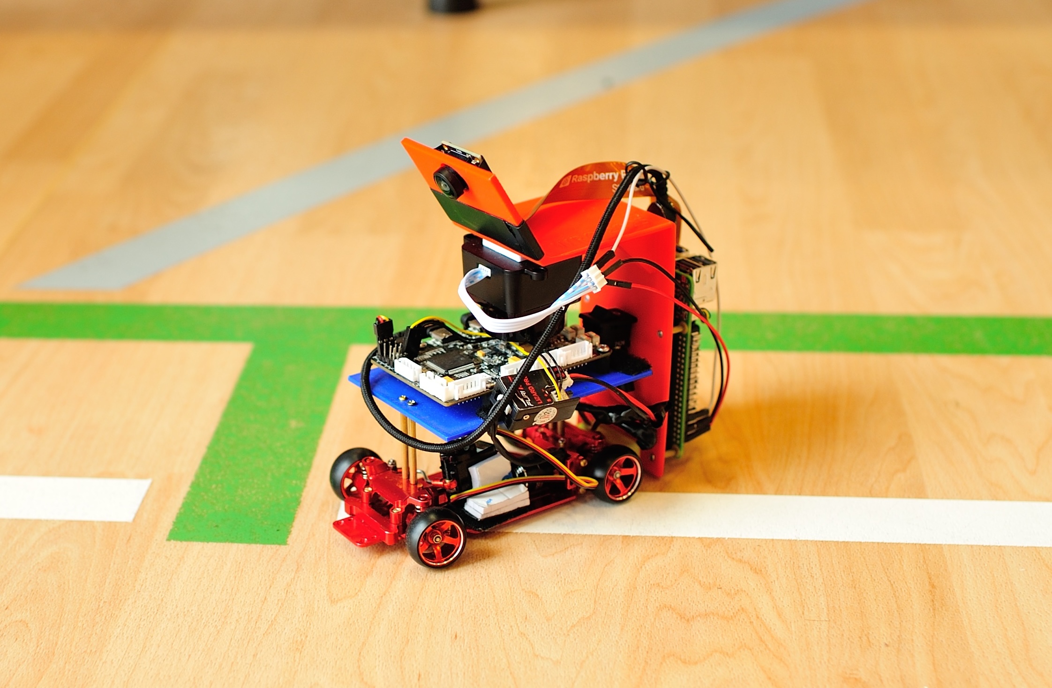
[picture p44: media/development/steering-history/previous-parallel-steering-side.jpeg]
Side view of the previous-year vehicle with parallel steering.
|  |  |

*Figure 1: Previous-year vehicle using parallel steering. Although its body was small, its limited front-wheel angle required repeated manoeuvres in the parking area and made boundary contact more likely.*

| Reference vehicle: overview | Reference vehicle: right side | Reference vehicle: front |
|---|---|---|
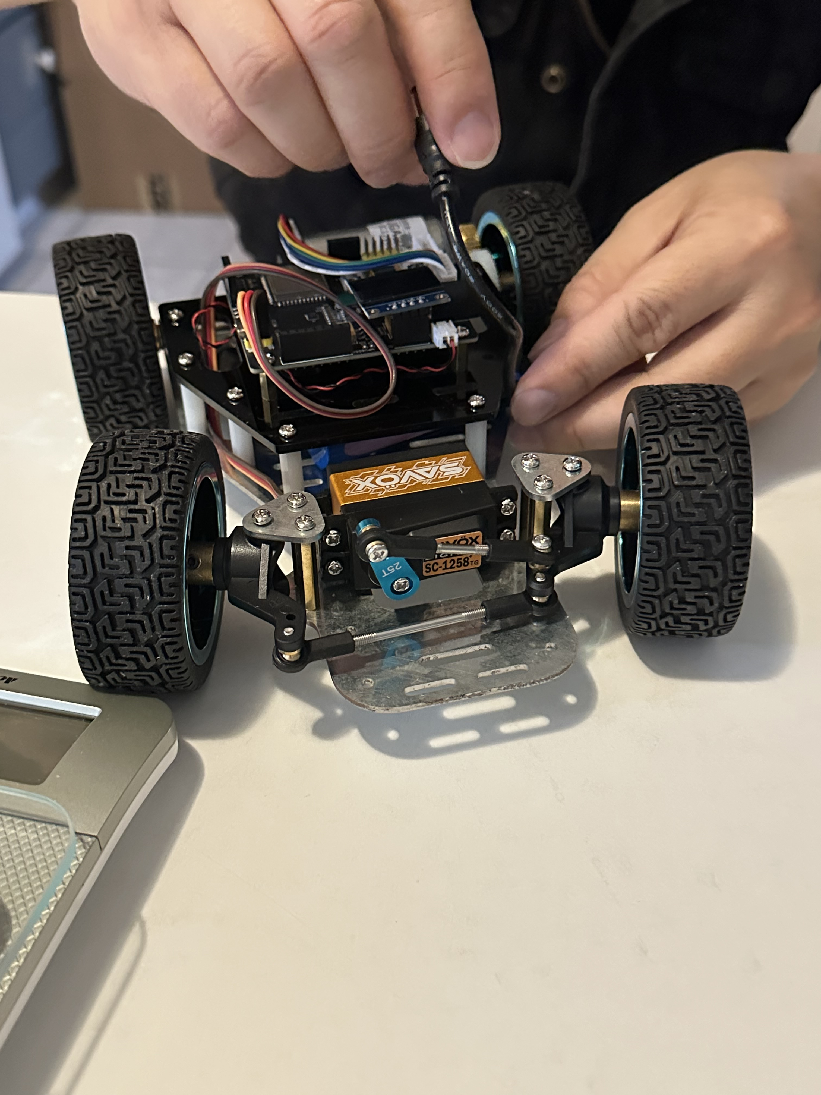
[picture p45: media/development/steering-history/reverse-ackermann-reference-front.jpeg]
Reference Reverse-Ackermann vehicle, front.
| Reference Reverse-Ackermann vehicle, overview. | Reference Reverse-Ackermann vehicle, right side. |  |

| Reference vehicle: steering assembly | Reference vehicle: front servo and battery display | Reference vehicle: motor |
|---|---|---|
| Reference Reverse-Ackermann vehicle, steering assembly. | Reference Reverse-Ackermann vehicle, front servo and battery display. | Reference Reverse-Ackermann vehicle, motor. |

*Figure 2: Reverse-Ackermann reference vehicle considered by the team. The photographs record its overall, steering, drive, front, and rear arrangement; after comparison, this vehicle uses positive Ackermann rather than directly reusing its steering geometry.*

Positive Ackermann, parallel steering, and Reverse Ackermann differ in the relationship between inner- and outer-front-wheel angles. In positive Ackermann, the inner front wheel turns farther than the outer wheel, so the extended wheel axes more closely meet at the same instantaneous turn centre on the rear-axle line; this suits the vehicle's low-speed, small-radius continuous turns. In parallel steering, both wheels use the same angle. Reverse Ackermann gives the outer front wheel a greater angle than the inner wheel. The latter can be used in vehicles that account for high-speed tyre slip angles and load transfer, but those are not this vehicle's design goals. It would not solve the previous vehicle's limited steering angle and repeated manoeuvres, nor match the team's priority of reducing low-speed tyre scrub and passing a `90°` turn stably.

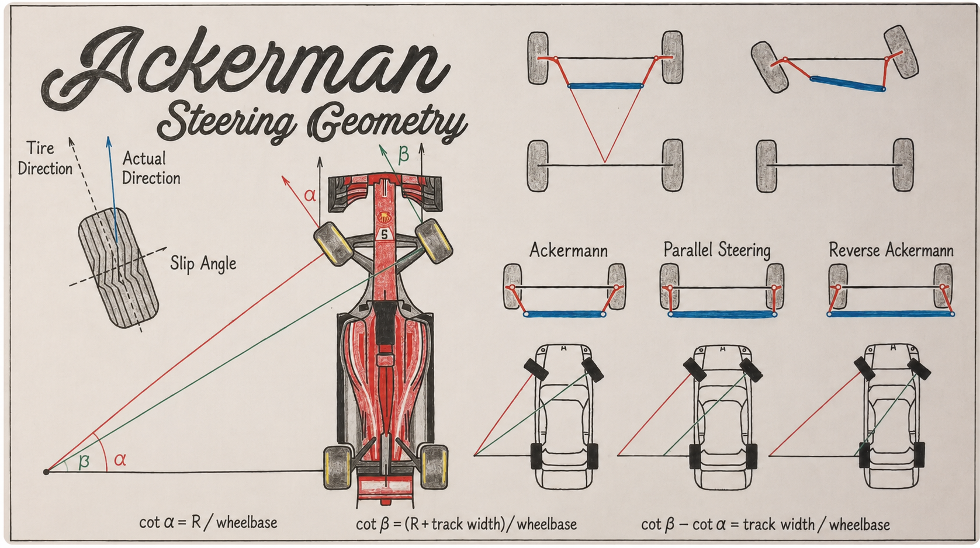
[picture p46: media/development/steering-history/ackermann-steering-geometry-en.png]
English steering-geometry explanation for positive Ackermann, parallel steering, and Reverse Ackermann.


*Figure 3: Steering geometry and instantaneous turn-centre explanation. The extended front-wheel axes in positive Ackermann more closely point to the same turn centre; parallel steering and Reverse Ackermann use different angle relationships.*

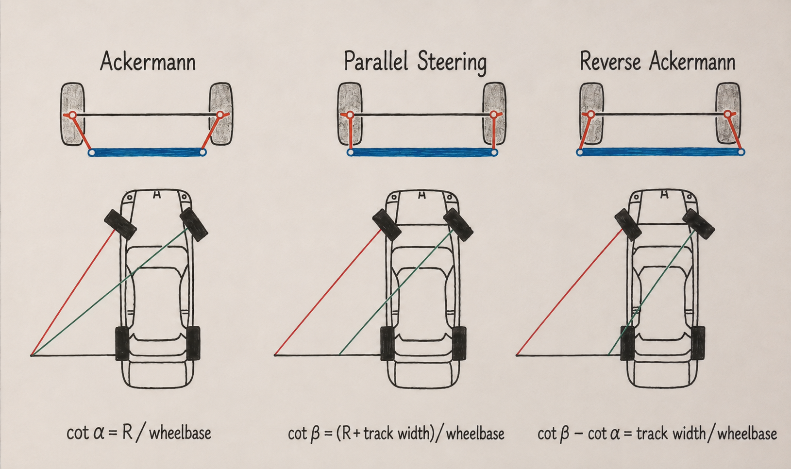
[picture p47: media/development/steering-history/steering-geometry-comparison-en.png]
English comparison of positive Ackermann, parallel steering, and Reverse Ackermann.


*Figure 4: Comparison of the three steering modes. The team selected positive Ackermann for low-speed, stable, compact `90°` turns.*

| Final V3: front | Final V3: left side |
|---|---|
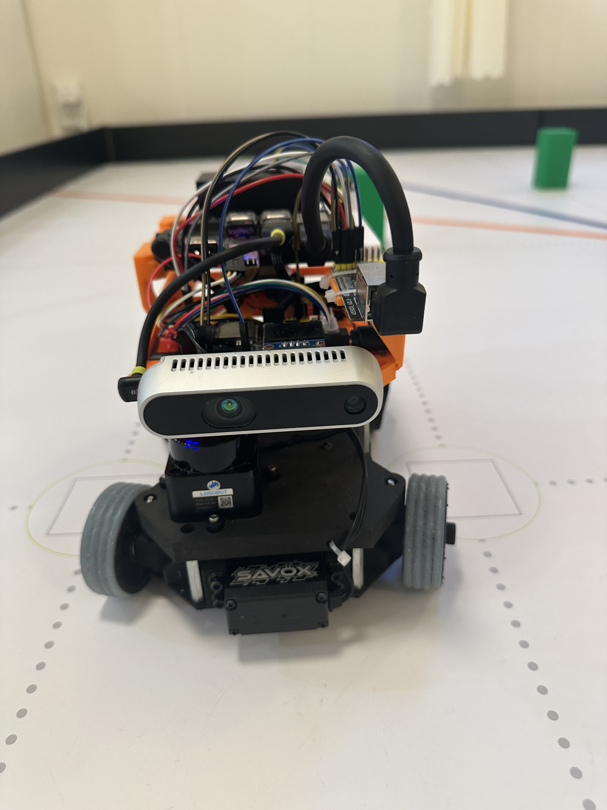
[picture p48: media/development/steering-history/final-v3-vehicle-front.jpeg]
Front view of this year's final V3 vehicle.
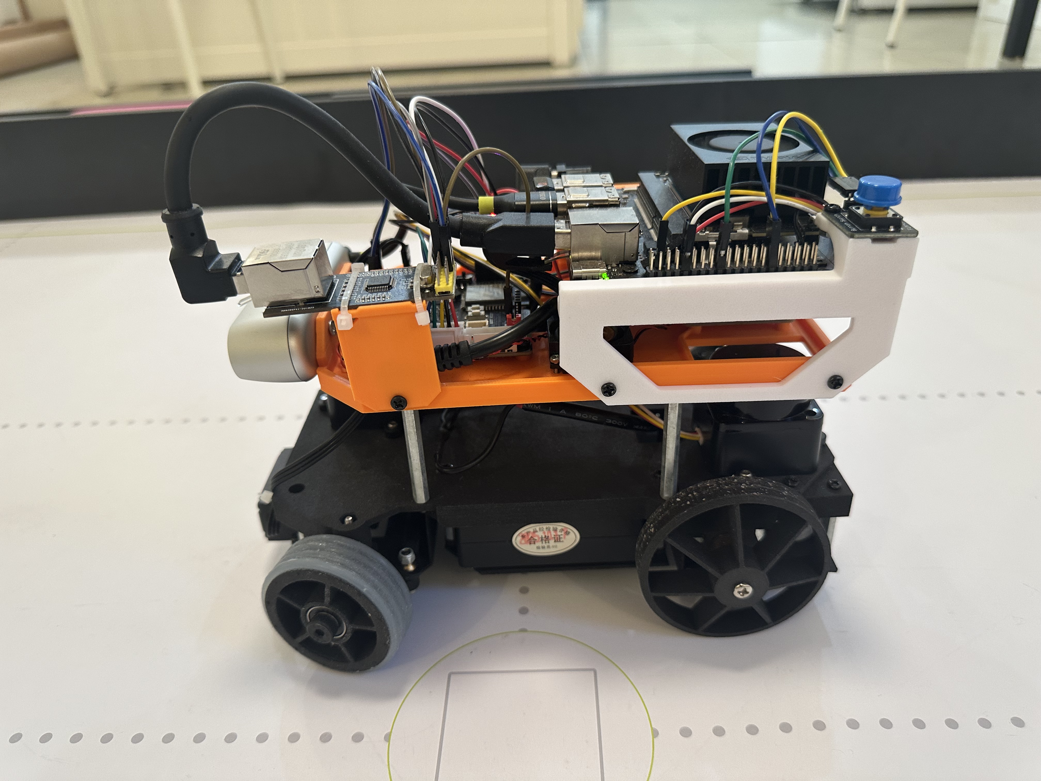
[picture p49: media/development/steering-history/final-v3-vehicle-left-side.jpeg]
Left-side view of this year's final V3 vehicle.
|  |  |

| Final V3: right side | Final V3: rear |
|---|---|
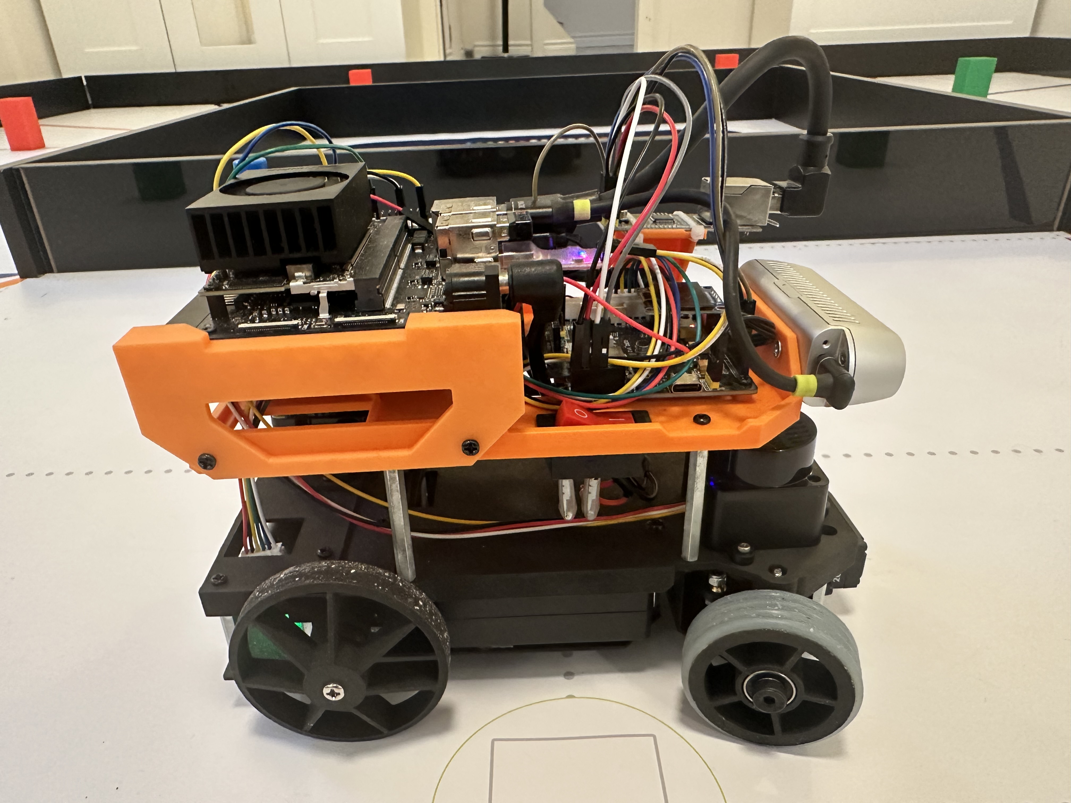
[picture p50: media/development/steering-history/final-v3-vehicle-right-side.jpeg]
Right-side view of this year's final V3 vehicle.
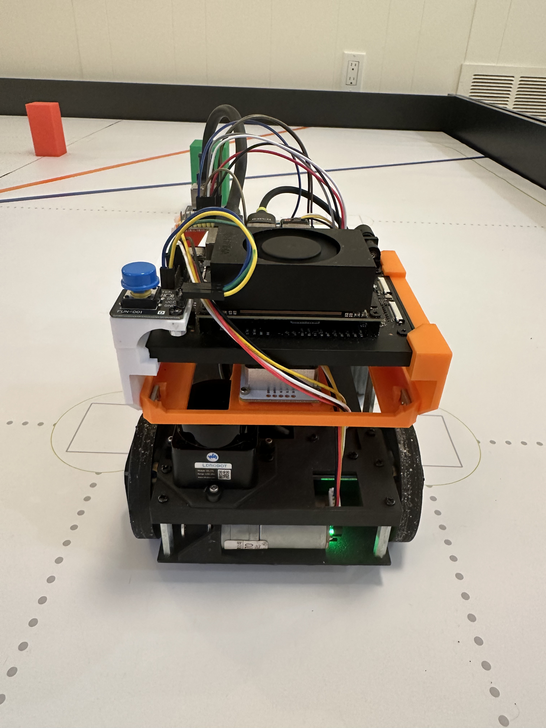
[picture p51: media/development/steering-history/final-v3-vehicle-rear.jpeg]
Rear view of this year's final V3 vehicle.
|  |  |

*Figure 5: This year's final V3 vehicle, in order: front, left side, right side, and rear.*

### 2. Using the complete swept envelope, not one radius, for the `375 mm` turn space

The team used the approximately `375 mm` narrowest turning area in the `3 m × 3 m` WRO game area as a chassis-geometry constraint. V1 was initially designed at `268 mm` long and `183 mm` wide so that it could turn out of the parking area more comfortably, while remaining within the competition's `300 mm × 200 mm` outer limit. During design, however, the team found that the space occupied in a `90°` turn is determined by the vehicle's complete swept path. V2 then changed the body to `220 mm × 176 mm × 150 mm`; V3 retained the `220 mm` length and narrowed the body further, producing the current `220 mm × 120 mm × 158 mm` body basis.

#### Theoretical rear-axle-centre turning radius

Using the rear-axle centre in the bicycle model:

$$
R = \frac{L}{\tan \delta}
$$

Here, $R$ is rear-axle-centre turning radius, $L$ is wheelbase, and $\delta$ is the equivalent front-wheel steering angle. The expression shows that theoretical radius is directly reduced by a shorter wheelbase or a larger steering angle. For example, at the same maximum angle of $45°$, $\tan 45° = 1$, so $R=L$; changing the wheelbase from `145 mm` to `138 mm` changes the theoretical radius only from `145 mm` to `138 mm`, a reduction of approximately `4.8%`.

The change from `268 mm` to `220 mm` body length should therefore not be simplified as “a much smaller turning radius.” The shorter body enabled a shorter wheelbase and overhangs, while the narrower body directly reduced lateral sweep during a turn.

#### Body-size comparison

| Comparison | V1 | V2 | V3 / current body basis |
|---|---:|---:|---:|
| Body outline | `268 mm × 183 mm` | `220 mm × 176 mm` | `220 mm × 120 mm` |
| Body height | — | `150 mm` | `158 mm` |
| Body diagonal | `324.5 mm` | `281.7 mm` | `250.6 mm` |
| Straight-line width remaining within `375 mm` | `192 mm` | `199 mm` | `255 mm` |

From V1 to V2, body length decreased by `48 mm` and width by `7 mm`. From V2 to V3, the `220 mm` length was retained while width decreased by a further `56 mm`. Therefore, relative to V1, final V3 is `63 mm` narrower and has an approximately `22.8%` smaller geometric body-outline diagonal; when centred, its straight-line each-side margin increases from `96 mm` to `127.5 mm`.

Reducing width from `183 mm` to `120 mm` moves each outer body edge `31.5 mm` closer to the centreline, directly reducing the outer front-corner sweep. Reducing length from `268 mm` to `220 mm` also shortens the overhangs: in a turn, the outer front-corner path reaches farther than the wheel path, so front overhang cannot be ignored.

For rear-axle-centre radius $R$, body width $W$, distance $A$ from rear axle to the foremost body point, and rear overhang $B$, the following expressions record an approximate full-vehicle sweep:

$$
R_{outer} = \sqrt{\left(R+\frac{W}{2}\right)^2+A^2}
$$

$$
R_{inner} = \sqrt{\left(R-\frac{W}{2}\right)^2+B^2}
$$

$$
\text{Swept width}=R_{outer}-R_{inner}
$$

Here $A=L+\text{front overhang}$, not wheelbase alone. The diagonal and straight-line margins compare the two body outlines intuitively; the final `90°` continuous-turn judgment uses a swept path that includes tyres, overhangs, and steering angle.

#### Conclusion: final V3 advantages in the `375 mm` turn space

V2 was the intermediate version moving from V1 toward a compact body; V3 is the final competition version. V3's advantage is not simply a smaller theoretical rear-axle turning radius. Its smaller full-vehicle swept envelope results from both the V1 → V2 reduction in body length and the V2 → V3 substantial reduction in width:

- From V1 to V2, body length decreased from `268 mm` to `220 mm` and wheelbase from `145 mm` to `138 mm`, enabling shorter front and rear overhangs. This reduces the maximum outer front-corner sweep radius and leaves more room for the inner rear wheel to cut in.
- V2 was `176 mm` wide; V3 reduced this further to `120 mm`. Each V3 outer edge therefore moves `28 mm` inward relative to V2 and `31.5 mm` inward relative to V1, directly reducing the outer front-corner sweep toward walls or obstacles.
- Body-outline diagonal decreases from `324.5 mm` to `250.6 mm`, while the straight-line margin relative to `375 mm` width increases from `50.5 mm` to `124.4 mm`. This is not a strict `90°` turn criterion, but it clearly shows that the final body has substantially more space for attitude adjustment.
- The positive-Ackermann front axle gives the inner front wheel a larger angle than the outer wheel. Together with the compact body, it reduces tyre scrub and unnecessary sweep in low-speed continuous turns.

The final V3 design advantage is therefore more geometric margin for the outer front corner, inner rear wheel, and steering error in an approximately `375 mm` narrow turn, making a continuous `90°` turn easier while retaining installation space for the front axle, rear drive, battery, and LiDARs.

### 3. Rules 11.5 and 11.13 determine the rear-drive transmission

Rule 11.5 does not permit an electronic differential with one motor on each side, such as a differential-wheeled robot. Rule 11.13 permits at most two drive motors for forward and reverse motion; every drive motor must connect directly to the axle turning the drive wheels, or indirectly through a gear system, and the two motors need not connect to the drive wheels independently. This vehicle therefore uses no differential: one motor drives a shared rear axle.

The vehicle therefore uses one GA25-370 gearmotor with Hall encoders, a shared rear axle without a differential, and front-wheel steering. The motor's integrated `9.6:1` gearbox drives a `20T` timing pulley; the timing belt drives a `40T` pulley fixed to the shared rear axle, which drives both rear wheels forward or backward. ESP32 counts the Hall-encoder pulses and sends them to Jetson; Jetson calculates `/wheel/odometry` from cumulative pulses, steering position, and timestamps. Communication and odometry computation are documented in Chapter 3.

| Rear-drive installation: top front | Rear-drive installation: top right | Rear-drive installation: rear right |
|---|---|---|
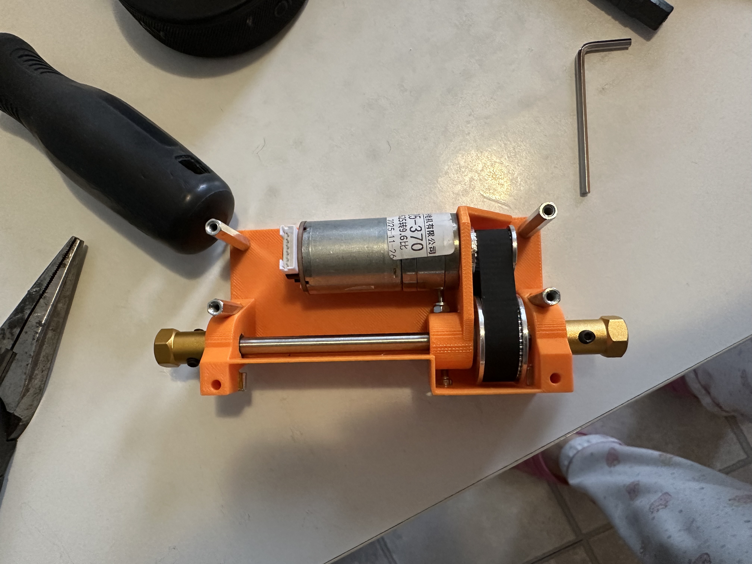
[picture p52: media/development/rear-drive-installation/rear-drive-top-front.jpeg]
Top-front view of the rear-drive motor and shared rear axle installation.
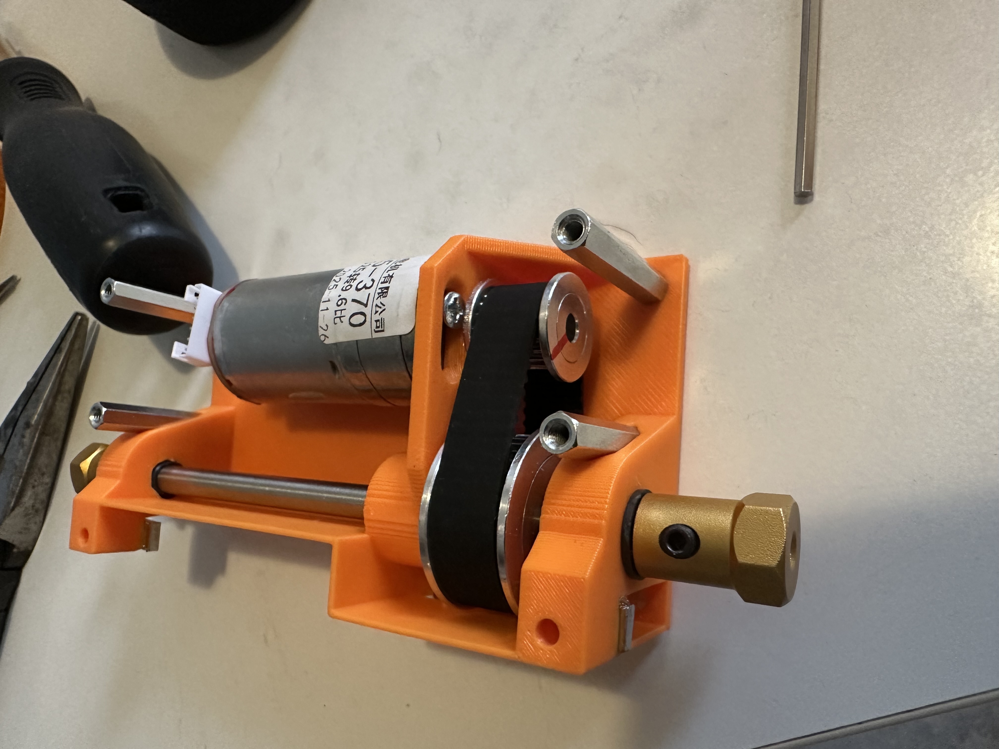
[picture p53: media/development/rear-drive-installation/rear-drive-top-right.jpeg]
Top-right view of the rear-drive motor and shared rear axle installation.
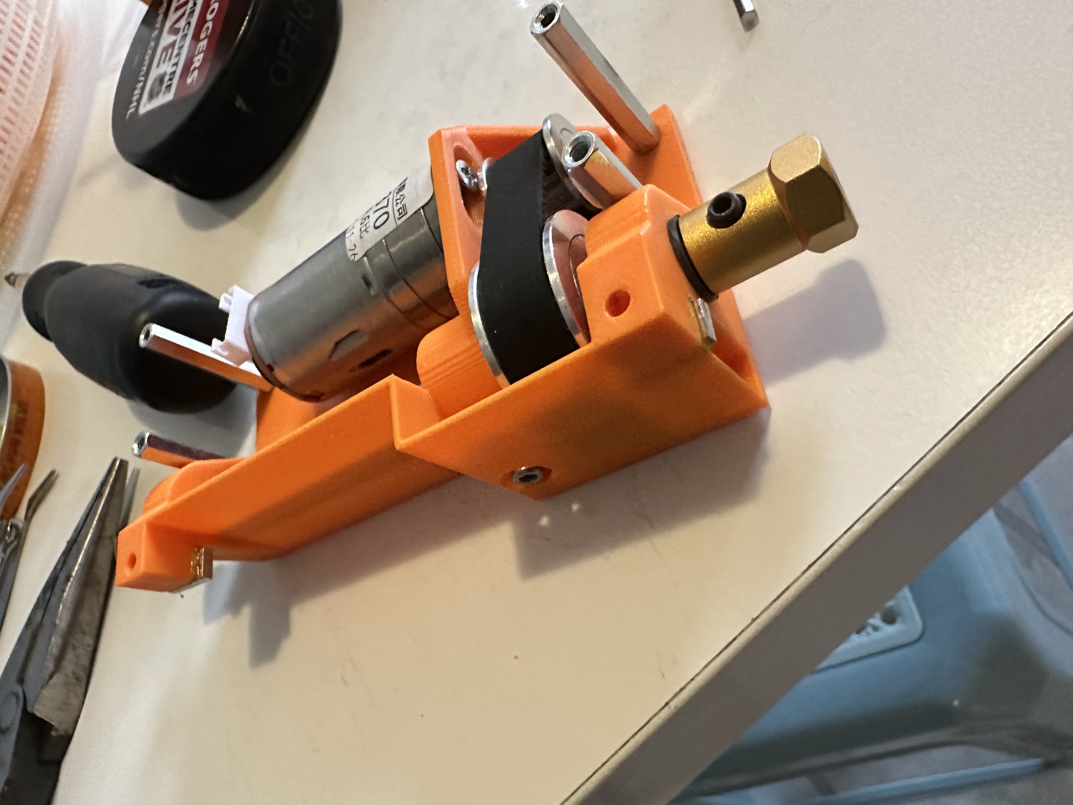
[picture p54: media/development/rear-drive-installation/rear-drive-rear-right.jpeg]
Rear-right view of the rear-drive motor and shared rear axle installation.
|  |  |  |

*Figure 6: Installed rear-drive motor, timing-belt transmission, and shared rear axle, in order: top front, top right, and rear right views.*

#### Rear-Drive Motor and Hall-Encoder Harness

| Item | Interface route | Cable and physical-test trade-off |
|---|---|---|
| GA25-370 rear-drive motor with built-in Hall encoder | ESP32 12 V motor/encoder interface → motor and Hall-encoder harness → GA25-370. | The included `20 cm` harness was too short for the internal routing path, so the final vehicle uses a `30 cm` harness. Hall-encoder pulses were read correctly in vehicle testing. The supplier warned that excessive harness length could prevent pulse readings, so the originally considered `50 cm` harness was not used. |

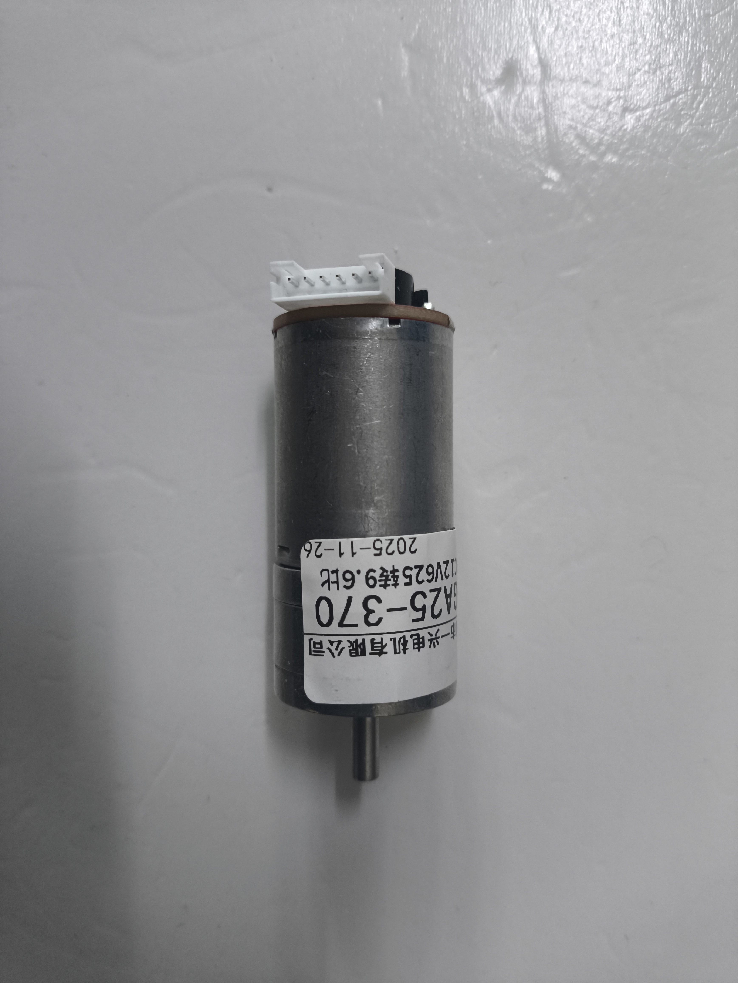
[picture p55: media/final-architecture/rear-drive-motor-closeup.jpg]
GA25-370 rear-drive motor with built-in Hall encoder.


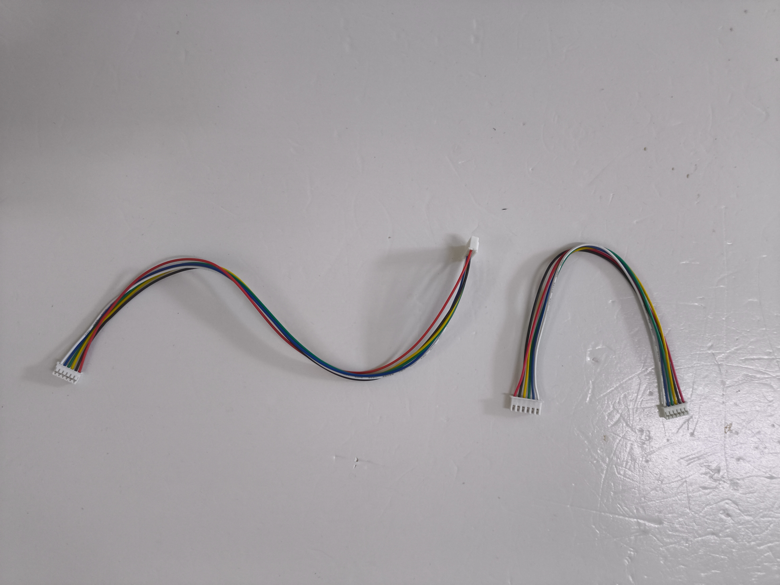
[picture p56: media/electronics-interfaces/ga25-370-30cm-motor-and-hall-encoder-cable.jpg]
Final 30 cm GA25-370 motor and Hall-encoder harness.


### 4. Tyre-drag trade-off for the shared rear axle without a differential

The vehicle has neither suspension nor a rear-axle differential, and its front end is slightly lighter. At large steering angles, the rear wheels must travel different distances while retaining equal angular speed; the early high-friction rear wheels produced drag and occasional slip. The team compared adding front-wheel ballast with using narrower, smoother rear wheels.

The final choice was the latter: smoother, `65 mm` 3D-printed rear wheels without an external silicone covering. Compared with the silicone-covered, higher-friction front wheels, the rear wheels permit the necessary low-speed slip and reduce shared-axle drag in turns. Tests reduced the effect of slip to a minimum, although a shared rear axle without a differential cannot eliminate it completely.

| Early high-friction treaded wheel | Final `65 mm` 3D-printed smooth rear wheel |
|---|---|
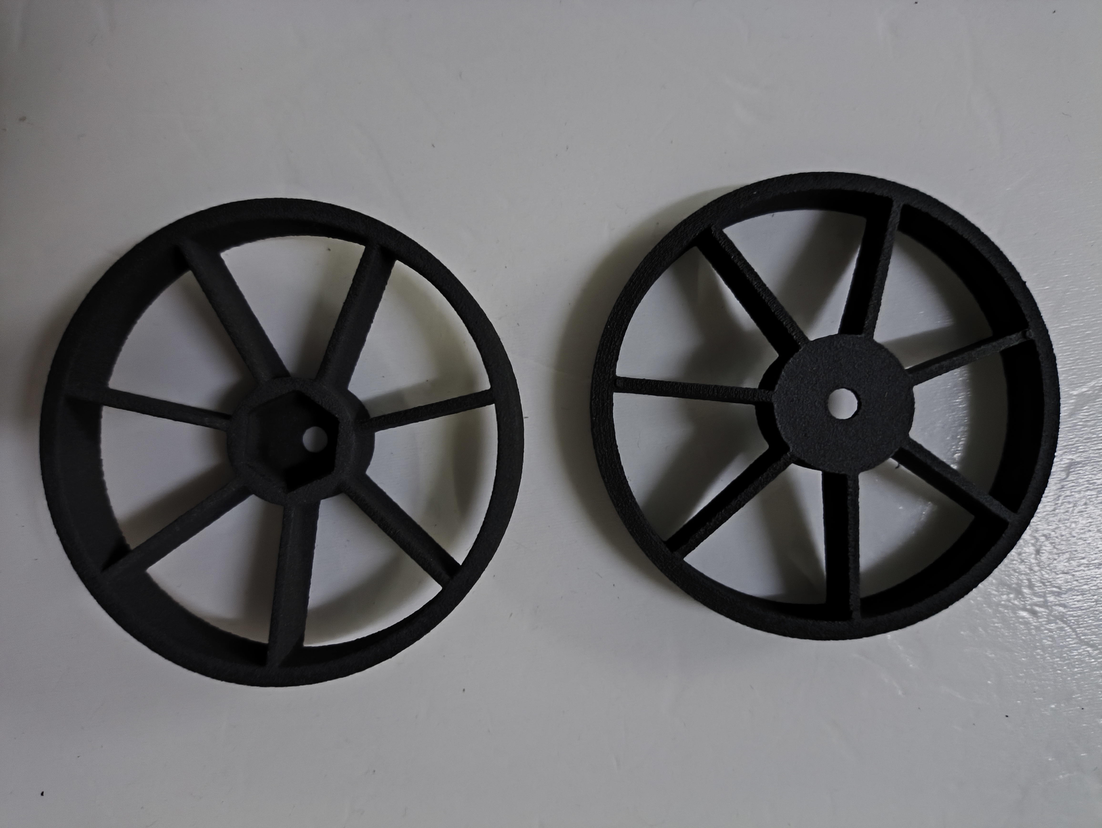
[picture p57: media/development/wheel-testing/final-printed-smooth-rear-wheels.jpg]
Final 65 mm 3D-printed smooth rear wheel.
| Early high-friction treaded wheel. |  |

*Figure 7: Rear-wheel trade-off. Left: the early high-friction treaded wheel. Right: the final `65 mm` 3D-printed smoother rear wheel without an external silicone covering.*

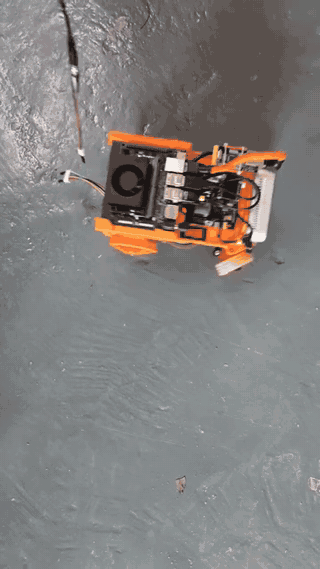
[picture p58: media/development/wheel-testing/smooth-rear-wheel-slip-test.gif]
Circular-driving test GIF after adopting the smooth rear wheels.


*Figure 8: Circular-driving test after adopting the smooth rear wheels, used to observe whether the shared rear axle without a differential still slips during low-speed turns.*

### 5. Competition start rules determine the single battery and low battery bay

Competition rules permit one switch to start the complete vehicle. After power-on, the vehicle must wait for one start button. The button may be on the main SBC/SBM or installed separately, but only one start button is permitted. There are therefore two opportunities to touch the vehicle in a run: first to power the whole vehicle, then to press the program-start button.

The vehicle uses both an ESP32 (SBM) and a Jetson Orin Nano Super Developer Kit (SBC). The early design used two batteries; to meet the one-switch whole-vehicle start rule, the team abandoned that arrangement and uses one `12 V` battery for both controllers.

| Early V3 dual-battery layout | Final single-battery, flag-terminal, and main-switch layout |
|---|---|
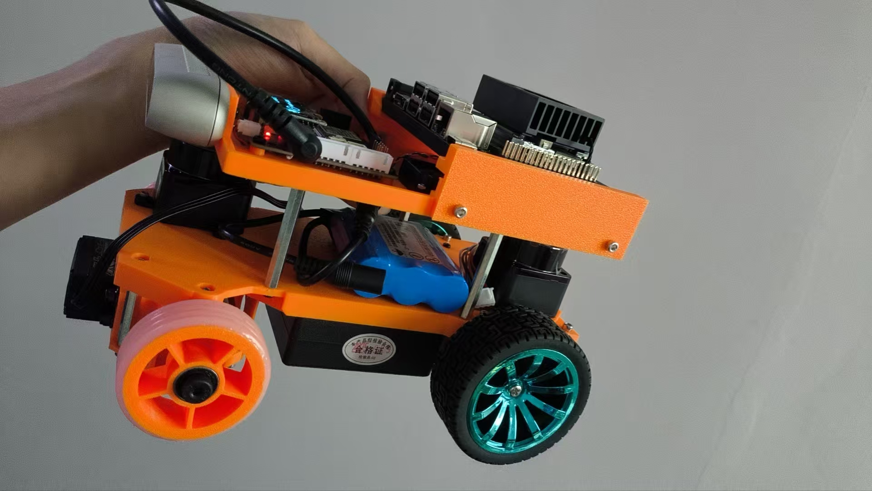
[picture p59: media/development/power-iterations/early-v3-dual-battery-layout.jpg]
Early V3 dual-battery layout.
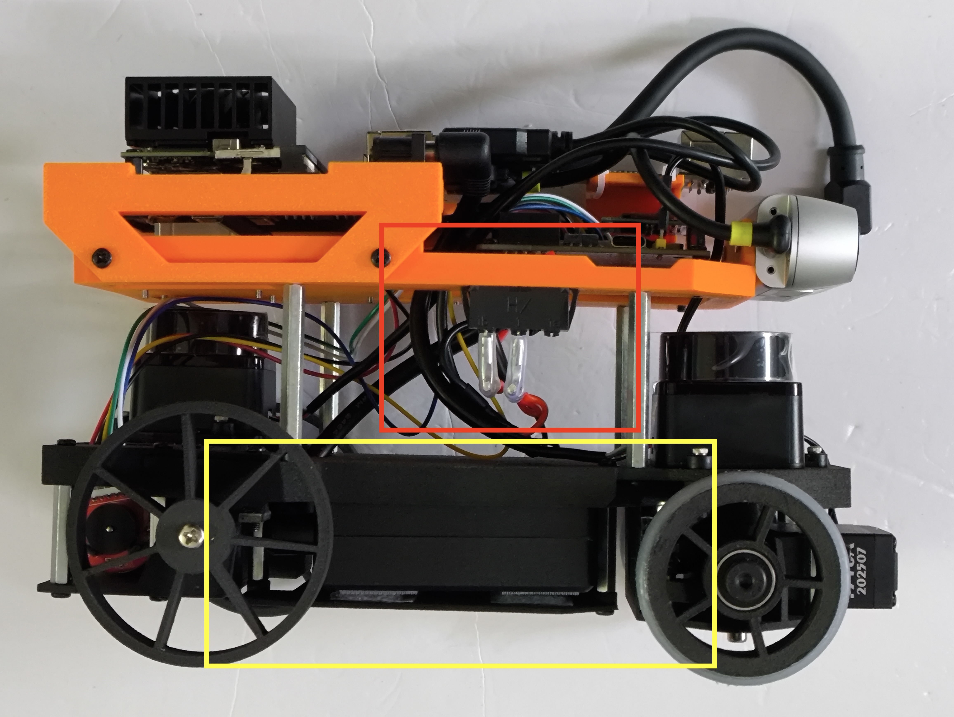
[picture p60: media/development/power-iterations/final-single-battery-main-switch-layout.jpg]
Final single-battery, flag-terminal, and main-switch control arrangement.
|  |  |

*Figure 9: Power-architecture iteration. Left: early dual-battery layout. Right: final arrangement in which one `12 V` battery, flag terminals, and one main switch power both controllers.*

Jetson input can be up to `19 V`, so the team considered a `12 V → 19 V` boost module. The module added vehicle mass, and testing showed that the existing program could run without the boost, so it was not adopted.

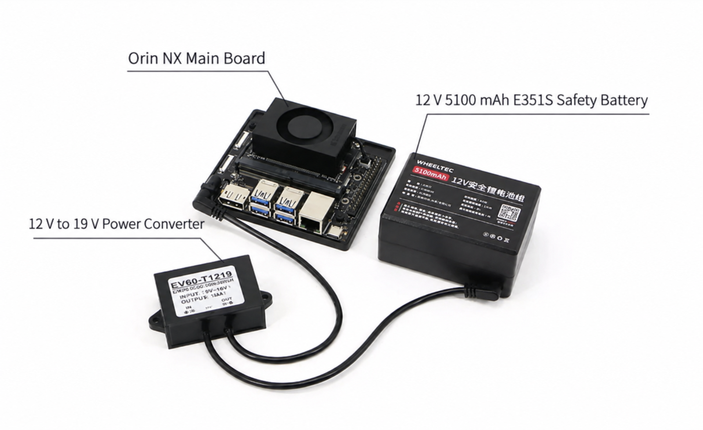
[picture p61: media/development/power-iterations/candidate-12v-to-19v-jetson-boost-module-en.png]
Evaluated 12 V to 19 V Jetson boost-module arrangement.


*Figure 10: Evaluated `12 V → 19 V` Jetson boost-module and `12 V` battery arrangement. It was not adopted because it added mass and the existing program ran without the boost.*

The battery bay sits in the lowest layer between the front and rear axles, keeping the battery low and providing a stable centre of gravity. Lower-layer mounting holes also connect the upper SBC, SBM, and other modules. Power distribution, the main switch, and the start button are detailed in Chapter 5.

### 6. `100 mm` course objects determine LiDAR scan height and ground clearance

Inner and outer course walls are `100 mm` high; red and green traffic signs are `50 mm × 50 mm × 100 mm`; parking limits are `200 mm × 20 mm × 100 mm`. The vehicle uses two LDROBOT STL-27L 2D LiDARs. The model and parameters are available from the [purchase page](https://detail.tmall.com/item.htm?id=722272898658) and the [LDROBOT STL-27L specification](https://www.ldrobot.com/technology).

| STL-27L product parameter | Significance for this vehicle |
|---|---|
| `DTOF` (Direct Time of Flight) | The LiDAR emits pulsed laser light and measures the reflected light's round-trip time $\Delta t$, calculating distance in that direction as $r=c\Delta t/2$; ranging does not rely on the coloured texture of course objects. |
| `360°` horizontal scan and `10 Hz` scan rate | Each LiDAR continuously changes its emission direction in one horizontal plane at a fixed height; one full rotation forms one two-dimensional radial distance scan. |
| `21,600 Hz` ranging frequency and typical `0.167°` angular resolution at `10 Hz` | Dense angle–distance samples are acquired in each rotation for the planar outlines of walls, corridor boundaries, and obstacles. |
| Rated `0.03–25 m` ranging range; `±15 mm` mean error at `0.03–2 m` | Covers the short-range walls and signs in the WRO course; actual processing range is set by task needs and software thresholds. |
| Native `UART @ 921600`, typical `5 V` supply, and approximately `45 g` mass | The two LiDARs total approximately `90 g`; this vehicle connects them to Jetson through USB-to-serial links. Physical interfaces are documented in Chapter 3. |
| `60 klux` ambient-light immunity | Helps retain laser-ranging availability in bright indoor conditions. |

DTOF explains **how distance is measured**, while “2D” describes **the spatial plane in which the distance is measured**: the ranging core rotates in a horizontal plane at the fixed vehicle height $h$. At each horizontal angle $\theta$, it emits a laser pulse, measures distance $r$ in that direction, and turns to the next angle; after a full rotation it has a set of $\{\theta,r\}$. This is a two-dimensional distance scan at a fixed height, which downstream nodes can use as a planar representation of walls, corridors, and obstacles. It is not a 3D point cloud that covers the object height.

```mermaid
flowchart LR
    A["Ranging core rotates in a horizontal plane at fixed height h"] --> B["Current azimuth θ: emit a pulsed laser"]
    B --> C["Object surface reflects the laser"]
    C --> D["DTOF measures round-trip time Δt"]
    D --> E["Calculate distance r = cΔt / 2"]
    E --> F["Record planar sample (θ, r, h)"]
    F --> G{"Has one full 360° rotation completed?"}
    G -- "No: turn to next azimuth θ + Δθ" --> B
    G -- "Yes" --> H["Output 2D LaserScan"]
    H --> I["Merge two LiDAR scans and publish /scan"]
```

Whether the scan plane intersects an object determines whether that object produces a range return in the 2D scan. Both LiDARs are installed below `95 mm`; their scan planes are approximately `85 mm` high. The plane therefore crosses the `0–100 mm` physical height of the walls, traffic signs, and parking limits and can return their two-dimensional distance outlines. If the scan plane is above `100 mm`, the laser passes over the object and the 2D LiDAR receives no range data from it.

```mermaid
flowchart TB
    A["Course walls, traffic signs, and parking limits are 100 mm high"] --> B{"Does the fixed-height scan plane h cross the object?"}
    C["Final scan plane: h ≈ 85 mm\ninstallation height below 95 mm"] --> B
    B -- "Yes" --> D["Obtain a two-dimensional range return from the object"]
    B -- "No: scan plane above 100 mm" --> E["Laser passes over the object\nthe object is absent from the 2D scan"]
    F["Early 20 mm ground clearance would raise chassis and LiDAR"] --> E
    G["Final 7 mm ground clearance"] --> C
```

Retaining the early `20 mm` chassis clearance would have raised the complete LiDAR-carrying chassis and therefore raised the scan planes too high. To preserve the below-`95 mm`, approximately `85 mm` scan height, chassis ground clearance was reduced from `20 mm` to `7 mm`; this makes chassis contact more likely on uneven ground.

### 7. Mass limit, 3D-point-cloud need, and rear coverage determine the dual-2D-LiDAR layout

Rule 11.2 limits complete vehicle mass to `1.5 kg`. The team originally preferred one 3D LiDAR primarily because it acquires spatial points at multiple vertical angles and therefore produces a 3D point cloud with height information; `360°` horizontal coverage is an additional advantage. Compared with a 2D LiDAR fixed to one horizontal scan plane, a 3D point cloud more conveniently associates the same calibration board or environmental feature with both camera-image coordinates and LiDAR spatial coordinates, enabling camera–LiDAR extrinsic calibration.

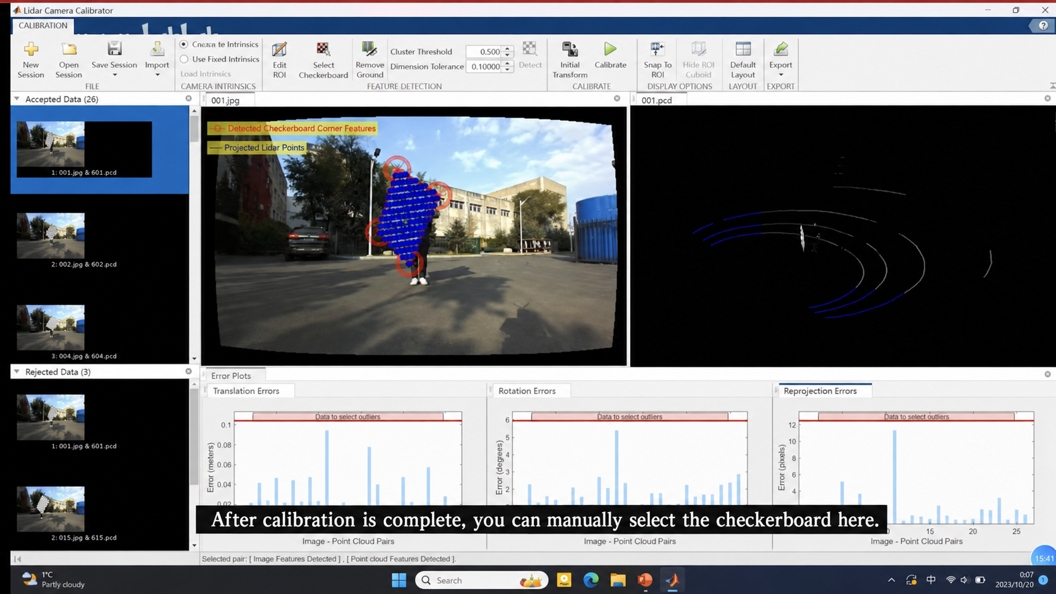
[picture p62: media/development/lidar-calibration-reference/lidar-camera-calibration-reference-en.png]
Camera–LiDAR calibration tool reference


Figure 11: Reference view from a camera–LiDAR calibration tool. Checkerboard corners in the camera image can be associated with 3D LiDAR points; this figure explains the calibration convenience of a 3D point cloud and is not a runtime record of this vehicle completing that calibration.

However, the lightest candidate 3D LiDAR was approximately `210 g`; the complete vehicle with competition battery already weighs `1.45 kg`, leaving no mass budget for that sensor. Two 2D LiDARs total approximately `90 g`, so the final design abandons the 3D-point-cloud approach, uses dual 2D LiDARs, and merges their scans in ROS 2.

The second LiDAR also fills the rear-area perception gap from the previous year's vehicle. To reduce complete overlap between the two scan planes, front and rear LiDARs are offset along the vehicle length rather than placed on the same longitudinal line; the rear LiDAR is raised on a `5 mm` 3D-printed spacer. This arrangement still produces two independent 2D horizontal scans; the merge node combines them into `/scan` for wall, corridor, and obstacle handling. Software interfaces and runtime visualisation are documented in Chapter 3.

### 8. Material, mass, and wheel-type rules determine the lightweight layered chassis

Rules 11.18 and 11.19 permit 3D printing, CNC machining, acrylic, wood, metal, and any other material; they do not restrict a particular construction system. Rule 11.2 limits the complete vehicle to `1.5 kg`, and Rule 11.4 prohibits every type of caster, ball caster, or spherical wheel. The inventory below totals `871.49 g` for its listed electronics, actuators, and batteries. It includes the motor, servo, and two batteries, so it must not be described as “more than `900 g` of sensors and computing hardware”; it also excludes the chassis, wheels, transmission, wiring, and fasteners. The chassis therefore still had to be lightweight while retaining a four-wheel, front-steering and rear-drive layout.

| Listed component | Quantity × unit mass | Subtotal |
|---|---:|---:|
| SC-1258TG+ steering servo | `1 × 64 g` | `64 g` |
| GA25-370 DC motor | `1 × 110 g` | `110 g` |
| D435f depth camera | `1 × 80 g` | `80 g` |
| TM171 IMU | `1 × 19 g` | `19 g` |
| STL-27L 2D LiDAR | `2 × 46.1 g` | `92.2 g` |
| Jetson Orin Nano Super Developer Kit | `1 × 176 g` | `176 g` |
| Jetson-side 12 V battery (inventory entry) | `1 × 184 g` | `184 g` |
| ESP32 development board | `1 × 35 g` | `35 g` |
| `0.96 in` OLED | `1 × 1.29 g` | `1.29 g` |
| ESP32-side 12 V battery (inventory entry) | `1 × 110 g` | `110 g` |
| **Listed-component total** | `64 + 110 + 80 + 19 + (2 × 46.1) + 176 + 184 + 35 + 1.29 + 110` | **`871.49 g`** |

The [component mass budget](../hardware/mechanical/calculations/weight-budget.csv) contains the calculation. The speaker is treated as negligible as specified by the team. W5500, CP2102, chassis, wheels, timing belt, wiring, fasteners, and printed parts are not yet included, so this is not the final measured vehicle mass.

The team considered a metal chassis for its stiffness, but rejected it to control total mass and adopted a fully 3D-printed chassis. PLA structural parts used for a long time in the previous year softened and bent, so the lowest and second layers use nylon PA6-CF. It provides higher stiffness for the front axle, rear axle, and battery bay, but carbon-fibre-filled material is conductive. The upper layer that directly contacts the SBC, SBM, and other electronics remains PLA to retain electrical insulation.

### 9. Previous plastic transmission-gear failures determine metal components at the critical drive position

In the previous year, the plastic transmission gear between motor and bearing failed five times, and replacement parts eventually could no longer be purchased. This failure history showed that the position could not continue to rely on a plastic gear. The critical motor-to-rear-axle transmission position therefore uses metal gear/pulley components this year to improve durability under repeated running.

### 10. Mechanical division between front Ackermann steering and rear drive

“Front Ackermann” here means the **steering geometry** of the front wheels; it does not mean front-wheel drive. The team selected front positive-Ackermann steering and rear drive rather than requiring the front wheels to steer and drive simultaneously.

With front-wheel drive, motor torque would have to pass through the front axle while the front wheels still turn left and right. In addition to the servo, 3D-printed teardrop-shaped servo horn, drag link, tie rod, steering arms, and steering knuckles, the front axle would need added structures that continue transmitting torque during steering, such as drive half-shafts with universal or constant-velocity joints, steerable driven hubs, or an equivalent drivetrain. That would consume limited front-axle space, add mass, alignment requirements, and mechanical failure points, and complicate clearance between the steering linkage and driveline.

The final layout separates these tasks: the front axle converts servo output into the unequal positive-Ackermann angles of the inner and outer front wheels; the rear axle receives GA25-370 drive torque through the `20T:40T` timing belt and drives both rear wheels through the shared rear axle. The front axle therefore carries no drive transmission and the rear drivetrain does not pass through steering joints, making the structure more suitable for this vehicle's low-speed, compact, stable-turning target.

### 11. Steering-servo torque and response-speed selection

The front-axle servo does not drive the vehicle forward. It uses the 3D-printed teardrop-shaped servo horn, ball-joint drag link, tie rod, and left/right steering arms to overcome front-wheel steering resistance. Servo selection therefore compares both output torque and steering response time.

#### Steering-Servo Interface and Harness

| Item | Interface route | Cable and final connection |
|---|---|---|
| SC-1258TG+ steering servo | ESP32 5 V servo header → three-wire servo harness → SC-1258TG+. | `20 cm`; final configuration. Yellow is control, red is 5 V, and brown is GND. |

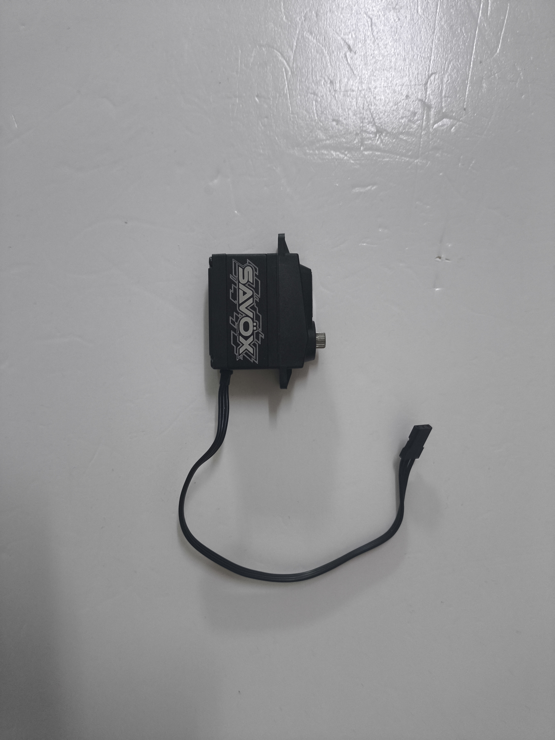
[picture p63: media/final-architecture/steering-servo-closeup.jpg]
SC-1258TG+ steering servo.


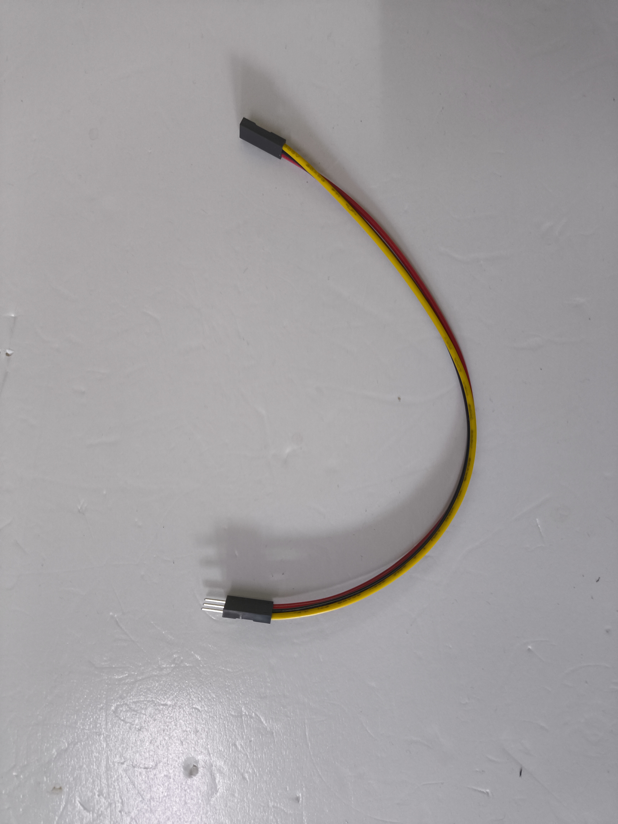
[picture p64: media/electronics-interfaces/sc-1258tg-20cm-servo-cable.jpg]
Final 20 cm three-wire servo harness for the SC-1258TG+.


In the product specifications, both candidates have dimensions of `40.3 mm × 20.2 mm × 37.2 mm`, mass `52.4 g`, titanium-alloy/aluminium gears, two bearings, and an aluminium case. Their principal difference is torque versus response speed:

| Servo | `4.8 V` torque / speed | `6.0 V` torque / speed | Selection meaning |
|---|---|---|---|
| SC-1256TG | `16.0 kgf·cm` / `0.18 s/60°` | `20.0 kgf·cm` / `0.15 s/60°` | Early AI-recommended high-torque candidate. |
| SC-1258TG+ | `9.6 kgf·cm` / `0.10 s/60°` | `12.0 kgf·cm` / `0.08 s/60°` | Final choice. The vehicle uses `4.8 V`; it takes `0.08 s` less per `60°` than SC-1256TG, a nominal response-time reduction of approximately `44.4%`. |

At the `4.8 V` specification used by this vehicle, SC-1258TG+ has `40%` less torque than SC-1256TG, but its `60°` travel time decreases from `0.18 s` to `0.10 s`. This vehicle follows a known map at low speed and needs to establish front-wheel angle promptly while turning and avoiding obstacles. At the measured straight-line steady speed of `0.319176 m/s`, the nominal `0.08 s` response-time difference corresponds to approximately `25.5 mm` less forward travel; at the planned mean speed of `0.14 m/s`, it corresponds to approximately `11.2 mm`. This is the direct advantage of the faster servo. Actual front-wheel steering time also depends on horn and linkage geometry, load, and supply voltage, so it cannot be equated directly with the servo's `60°` specification time.

#### From servo torque to steering-link force

Servo output torque first acts at the ball-joint connection of the 3D-printed teardrop-shaped servo horn. If the effective distance from that connection to the servo output axis is $r_h$, the drag-link push/pull force is:

$$
F_{\text{drag link}}=\frac{\tau_{\text{servo}}}{r_h}
$$

The SC-1258TG+ specified torques convert to:

$$
\tau_{\text{1258,4.8 V}}=9.6\ \text{kgf·cm}=0.941\ \text{N\,m}
$$

$$
\tau_{\text{1258,6 V}}=12.0\ \text{kgf·cm}=1.177\ \text{N\,m}
$$

The table converts those torques to push/pull force at several horn radii. It shows the relationship between lever arm and available force; it does not assume that any listed radius is the final CAD dimension.

| Effective servo-horn radius $r_h$ | `4.8 V` specified push/pull force | `6 V` specified push/pull force |
|---:|---:|---:|
| `10 mm` | `94.1 N` (approximately `9.6 kgf`) | `117.7 N` (approximately `12.0 kgf`) |
| `15 mm` | `62.7 N` (approximately `6.4 kgf`) | `78.5 N` (approximately `8.0 kgf`) |
| `20 mm` | `47.1 N` (approximately `4.8 kgf`) | `58.9 N` (approximately `6.0 kgf`) |

The drag link then acts through the steering arm on the steering knuckle. Let $r_s$ be the effective steering-arm lever, $\cos\phi$ the effective force-transmission factor for the drag-link/steering-arm angle, and $\eta_{link}$ the linkage efficiency. The steering moment available at one knuckle is:

$$
\tau_{\text{knuckle,available}}
=\tau_{\text{servo}}
\times\frac{r_s}{r_h}
\times\cos\phi
\times\eta_{link}
$$

The front wheel's steering-resistance moment depends on that wheel's normal load $N_{front}$, tyre-to-mat static-friction coefficient $\mu_s$, and scrub radius $r_{scrub}$:

$$
\tau_{\text{knuckle,required}}
=\mu_sN_{front}r_{scrub}
$$

To create a conservative upper bound independent of unmeasured front-axle load distribution, the calculation can treat the entire vehicle weight as acting on the front wheel and use the `25 mm` front-wheel radius as an upper bound for scrub radius. With $\mu_s=1$:

$$
\tau_{\text{knuckle,required}}
\le1\times(1.45\times9.81)\times0.025
\approx0.356\ \text{N\,m}
=3.63\ \text{kgf·cm}
$$

Even using the lower `4.8 V` specification, the SC-1258TG+ output of `9.6 kgf·cm` exceeds this conservative single-front-wheel steering-resistance bound. When it is transmitted to the steering knuckle, the mechanism remains above that bound provided its effective transmission ratio $\frac{r_s}{r_h}\cos\phi\eta_{link}$ is at least $3.63/9.6\approx0.378$; at the `6 V` specification the threshold is $3.63/12.0\approx0.303$. The final CAD horn-hole position, steering-arm hole position, and drag-link angle are used to check this transmission ratio.

SC-1258TG+ was therefore not selected merely because it is faster than SC-1256TG: its specified torque, transferred through the horn and steering arm, covers the conservative front-wheel steering-resistance boundary, while its shorter nominal response time better suits the vehicle's low-speed, compact continuous turns.

### 12. Required rear-drive torque and GA25-370 selection

Rear-drive selection starts from the tangential traction force required at the tyre, not directly from a motor's advertised “jin of force”. Wheel-axle torque is:

$$
\tau_{\text{wheel}}=F_{\text{traction}}\times r_{\text{wheel}}
$$

GA25-370 drives the rear wheels, so motor-torque calculation uses only the rear-wheel radius:

$$
D_r=65\ \text{mm},\quad r_r=32.5\ \text{mm}=0.0325\ \text{m}
$$

Traction force includes at least rolling resistance, acceleration force, and turning losses:

$$
F_{\text{traction}}=F_{\text{rolling}}+F_{\text{acceleration}}+F_{\text{turning losses}}
$$

Motor torque cannot necessarily be converted entirely into forward traction. The maximum tangential force that the rear drive wheels can transmit without slip is bounded by static friction:

$$
F_{\text{static,max}}=\mu_s N_{\text{rear}}
$$

Here $\mu_s$ is the static-friction coefficient between the rear tyres and the course, and $N_{\text{rear}}$ is the normal force carried by the two driven rear wheels; it is not simply the complete vehicle weight $mg$. The corresponding maximum rear-axle torque without slip is:

$$
\tau_{\text{rear axle, static,max}}
=\mu_s N_{\text{rear}}r_{\text{rear}}
$$

Usable forward traction is therefore:

$$
F_{\text{usable}}=\min\left(\frac{\tau_{\text{rear axle}}}{r_{\text{rear}}},\ \mu_s N_{\text{rear}}\right)
$$

If the wheel force commanded through the drivetrain, $\tau_{\text{rear axle}}/r_{\text{rear}}$, exceeds $\mu_sN_{\text{rear}}$, the rear tyres exceed static friction and slide relative to the mat, appearing as wheel spin or acceleration slip; additional motor torque no longer increases vehicle acceleration proportionally. The smoother rear wheels on this vehicle reduce shared-axle drag in turns without a differential, so straight-line acceleration must still be kept within the static-friction limit through the motor command and rear-axle load. The current record contains no separate measurement of rear-tyre-to-WRO-mat static friction or dynamic rear-axle load; the torque values below are therefore motor-and-drivetrain-capability calculations, not a measured tyre-traction limit.

Turns also introduce Ackermann-geometry error, non-differential rear-wheel scrub, tyre/course friction, bearing and timing-belt resistance, battery-voltage drop, and motor-efficiency loss. A first conservative magnitude estimate therefore uses a smooth course, `m=1.45 kg`, and rolling-resistance coefficient `C_{rr}=0.05`:

$$
F_{\text{rolling}}=C_{rr}mg=0.05\times1.45\times9.81\approx0.71\ \text{N}
$$

For low-speed straight rolling alone, required rear-axle torque is:

$$
\tau_{\text{rolling}}=0.71\times0.0325\approx0.023\ \text{N\,m}
\approx0.24\ \text{kgf\,cm}
$$

The `0.14 m/s` in Section 13 is the planned **mean run speed** derived from `14 m / 100 s`; it is not a starting acceleration. To estimate transient traction force when starting from rest, this calculation uses the team's original acceleration case of `a=0.5 m/s²`. If acceleration stops after reaching `0.14 m/s`, the time to reach that speed is:

$$
t=\frac{v}{a}=\frac{0.14}{0.5}=0.28\ \text{s}
$$

Starting torque at `a=0.5 m/s²` is:

$$
F_{\text{acceleration}}=ma=1.45\times0.5=0.725\ \text{N}
$$

$$
\tau_{\text{normal acceleration}}=(0.71+0.725)\times0.0325
\approx0.0466\ \text{N\,m}
\approx0.48\ \text{kgf\,cm}
$$

For comparison, the `a=1.0 m/s²` case represents a brief faster-start condition:

$$
\tau_{\text{faster acceleration}}=(0.71+1.45)\times0.0325
\approx0.070\ \text{N\,m}
\approx0.71\ \text{kgf\,cm}
$$

These values show that constant-speed rolling needs little torque, but a motor must not be selected from the constant-speed value alone: acceleration, turning, and transmission losses require margin.

#### Selected motor and timing-belt torque capability

The selected `12 V` GA25-370 uses an internal `9.6:1` gearbox. Its parameters are below; rated values are for normal continuous use, while maximum-load values are not a continuous operating target.

| Parameter | Value |
|---|---:|
| No-load current | `0.05 A` |
| Rated gearbox-output speed | `500 rpm` |
| Maximum no-load gearbox-output speed | `625 rpm` |
| Rated gearbox-output torque | `0.3 kgf·cm` = `0.0294 N·m` |
| Rated current / rated output power | `0.35 A` / `3 W` |
| Maximum-load gearbox-output torque | `1.2 kgf·cm` = `0.1177 N·m` |
| Maximum-load current / power | `1.5 A` / `6 W` |

The `20T:40T` timing belt halves rear-axle speed. With timing-belt efficiency $\eta=0.90$, rear-axle torque is:

$$
\tau_{\text{rear axle}}=\tau_{\text{gearbox output}}\times\frac{40}{20}\times\eta
$$

Rated rear-axle torque is therefore:

$$
0.3\times2\times0.90=0.54\ \text{kgf\,cm}
=0.0529\ \text{N\,m}
$$

Maximum-load rear-axle torque is:

$$
1.2\times2\times0.90=2.16\ \text{kgf\,cm}
=0.2118\ \text{N\,m}
$$

Compared with the design cases above, start acceleration at `a=0.5 m/s²` requires approximately `0.48 kgf·cm`, below the `0.54 kgf·cm` rated rear-axle torque. After reaching `0.14 m/s`, the vehicle enters the mean-speed, turning, obstacle-avoidance, and parking phases described in Section 13. Acceleration at `a=1.0 m/s²` requires approximately `0.71 kgf·cm`, above the rated value but below the maximum-load value, so it is not treated as a continuous operating target.

#### `0 → 150` straight-line test and torque calculation

To relate the torque estimate to vehicle motion, the team performed five straight-line tests on a flat WRO mat using the `4500 mAh` competition battery. The team also uses a smaller `2500 mAh` battery as a replacement in day-to-day work, but the five results here use the `4500 mAh` competition battery. Each test began with the vehicle at rest and steering command `0`; the motor-control command changed directly from `0` to `150`. `/wheel/odometry` recorded timestamps, linear speed, and path distance. Acceleration is the `10%–90%` rise of each run's steady speed, and the vehicle was stopped after its measured path reached at least `1 m`. Here, `150` is an ESP32 motor-control command, not an rpm, speed, or torque unit.

| Run | Delay before vehicle motion (s) | `10%–90%` acceleration (m/s²) | Steady speed (m/s) | Command-to-`1 m` time (s) |
|---:|---:|---:|---:|---:|
| 1 | `0.098` | `0.507` | `0.319` | `3.395` |
| 2 | `0.094` | `0.533` | `0.319` | `3.390` |
| 3 | `0.087` | `0.643` | `0.319` | `3.392` |
| 4 | `0.081` | `0.479` | `0.319` | `3.404` |
| 5 | `1.362` | `0.565` | `0.319` | `4.697` |

The five-run mean `10%–90%` acceleration is `0.545253 m/s²`, with sample standard deviation `0.063005 m/s²`; mean steady speed is `0.319176 m/s`. Run 5 had a longer delay before motion, but its acceleration and steady speed remained close to the other runs. The complete calculation parameters are in [torque-speed-calculations.csv](../hardware/mechanical/calculations/torque-speed-calculations.csv).

This test calculation uses $C_{rr}=0.03$ and rear-wheel radius `0.0325 m`:

$$
F_{\text{acc}}=ma=1.45\times0.545253=0.7906\ \text{N}
$$

$$
F_{\text{roll}}=C_{rr}mg=0.03\times1.45\times9.81=0.427\ \text{N}
$$

$$
T_{\text{rear axle, required}}=(F_{\text{acc}}+F_{\text{roll}})r
=1.2174\times0.0325=0.0396\ \text{N\,m}
$$

Converted to gearbox output:

$$
T_{\text{gearbox, required}}
=\frac{0.0396}{2\times0.90}=0.0220\ \text{N\,m}
$$

This is below the rated gearbox-output torque of `0.0294 N·m`, giving rated torque margin:

$$
\frac{0.0294}{0.0220}=1.34
$$

Therefore, these five tests correspond to rear-axle requirement `0.0396 N·m` (approximately `0.404 kgf·cm`), while theoretical rated rear-axle torque is `0.0529 N·m`. This is a straight-line vehicle-test dataset in addition to the Section 12 design cases; it does not substitute for loads during turns, obstacle avoidance, or parking.

#### How torque sets the selectable launch acceleration

At launch, the motor and transmission first convert rear-axle torque into rear-wheel traction force. Only the traction remaining after rolling resistance becomes vehicle acceleration:

$$
F_{\text{drive}}=\frac{\tau_{\text{rear axle}}}{r_{\text{rear}}}
$$

$$
a=\frac{F_{\text{usable}}-F_{\text{roll}}-F_{\text{turn}}}{m}
$$

Here $F_{\text{usable}}$ cannot exceed the tyre static-friction limit $\mu_sN_{\text{rear}}$; during straight launch $F_{\text{turn}}=0$. More torque therefore does not necessarily produce more acceleration: once $F_{\text{drive}}$ exceeds the static-friction limit, the rear wheels slip; during a turn, the shared rear axle also has additional drag.

Using rated gearbox-output torque `0.0294 N·m`, the `2:1` external reduction, and transmission efficiency `0.90`, the rated rear-axle torque is `0.0529 N·m`. Its theoretical wheel traction is:

$$
F_{\text{drive,rated}}=\frac{0.0529}{0.0325}\approx1.63\ \text{N}
$$

For a flat straight run with rolling resistance `0.427 N` from $C_{rr}=0.03$, and provided the tyres have enough static friction to transmit this force, the rated-torque theoretical launch-acceleration limit is:

$$
a_{\text{rated,straight}}=\frac{1.63-0.427}{1.45}\approx0.83\ \text{m/s}^2
$$

Therefore, `0.83 m/s²` is only the theoretical rated-torque boundary for a flat straight run; the usable acceleration changes during turns, obstacle avoidance, or changes in tyre traction. The design case uses `0.5 m/s²`, and the five straight-line tests average `0.545253 m/s²`, both below this flat-straight rated-torque boundary.

### 13. Run-time budget and rear-drive target speed

The three-minute run provides `180 s` in total. The team allocated `40 s` to parking and reserved a further `40 s` for unexpected events along the route, leaving `100 s` for obstacle driving. The four sides of the `3 m × 3 m` course total `12 m`; an additional `2 m` was added to cover turns, obstacle avoidance, and extra path length, giving a planned distance of approximately `14 m`. The required mean driving speed is therefore:

$$
v_{target}=\frac{14\ \text{m}}{100\ \text{s}}
=0.14\ \text{m/s}
=140\ \text{mm/s}
$$

This is not `14 mm/s`. It is first converted into the required wheel and transmission speed, not directly into a PWM command. For a `65 mm` rear wheel:

$$
C=\pi D=\pi\times0.065=0.2042\ \text{m}
$$

$$
n_{\text{rear axle}}=\frac{v_{target}\times60}{C}
=\frac{0.14\times60}{0.2042}
\approx41.1\ \text{rpm}
$$

The `20T:40T` timing belt makes rear-axle speed one half of gearbox-output speed, so:

$$
n_{\text{gearbox output}}=41.1\times\frac{40}{20}
\approx82.3\ \text{rpm}
$$

GA25-370 has an internal `9.6:1` reduction. This operating point corresponds to motor-rotor speed of approximately `82.3×9.6=790 rpm`, while the maximum no-load gearbox-output speed is `625 rpm`; the target requires `82.3 rpm`, approximately `13.2%` of that output limit. The `9.6:1` internal gearbox and `20T:40T` external reduction therefore have sufficient speed margin.

The same conversion applies to the measured steady speed. The five straight-line tests gave a mean steady speed of $v_{test}=0.319176\ \text{m/s}$:

$$
n_{\text{rear axle,test}}=\frac{0.319176\times60}{0.2042}
\approx93.8\ \text{rpm}
$$

$$
n_{\text{gearbox output,test}}=93.8\times\frac{40}{20}
\approx187.6\ \text{rpm}
$$

`187.6 rpm` is approximately `37.5%` of the motor's `500 rpm` rated gearbox-output speed and remains below the `625 rpm` maximum no-load output speed. The measured straight-line steady speed and the planned mean speed are therefore both within the selected motor's output-speed range.

Acceleration does not correspond to one fixed rpm; it corresponds to the rate at which rpm changes. At any instant, $n_{\text{rear axle}}=v\times60/C$, therefore:

$$
\frac{dn_{\text{rear axle}}}{dt}=\frac{a\times60}{C}
$$

Using the five-test mean acceleration $a=0.545253\ \text{m/s}^2$ and $C=0.2042\ \text{m}$ gives a rear-axle speed-rise rate of approximately `160.2 rpm/s`; after the `20T:40T` timing belt, the gearbox-output speed-rise rate is approximately `320.4 rpm/s`. For example, accelerating approximately from rest to `0.319176 m/s` takes $0.319176/0.545253\approx0.59\ \text{s}$. Thus, the acceleration calculation describes how rotational speed is established during launch, while the steady-speed calculation checks the rpm needed for sustained travel.

The firmware's `0–400` motor command only maps linearly to a `13-bit` PWM duty range of `0–8191`; it is not an rpm or speed unit. In flat WRO-mat tests, command `150` produced mean stable speed of `0.319176 m/s`, above the planned `0.14 m/s` mean; turns, obstacle handling, stops, and parking use the remaining time.

### 14. Cable management and protected routing

The previous-year vehicle had exposed cables that could be dragged into and contact obstacles. Cable routing was therefore designed together with chassis, sensor, and connector mounting positions rather than being fitted into leftover space after all hardware was installed. Each cable route is determined from the actual component location and connector direction: it must be long enough for plugging, maintenance, and necessary steering travel, but excess length must not form a loop outside the body outline. Routes must also avoid the steering front axle, rear wheels, timing belt, and ground.

| Component or link | Cable-length and routing decision | Chassis treatment |
|---|---|---|
| Front and rear LiDAR | Early layouts showed that wheels could block the LiDAR cable route. The front and rear LiDAR mounts were therefore separated along the vehicle length and routes upward were reserved for their cables. | Openings in the middle layer guide harnesses to the upper layer; cables remain inside the chassis and do not cross the wheels or the scan mounts. |
| D435f depth camera and TM171 IMU | Camera and IMU connector direction and installed position were decided before cable length. The IMU was reoriented from its original rear-to-front USB route so that its cable could be connected more easily. | The camera is on the centreline at the front of the upper layer and the IMU is on the adjacent raised layer. Their USB leads route along the upper layer and through the chassis to Jetson, without hanging from the front or side. |
| SC-1258TG+ servo | The supplied three-wire servo lead was long enough, so no custom extension was added; it routes from the front side to the MCU rather than crossing the front axle from the centre. | The wire rises outside the front-axle travel envelope, preserving clearance for the servo-linkage assembly. |
| Program-start button | The program-start button uses an approximately `10 cm` Dupont lead to Jetson GPIO. Its lead is determined separately from the button mounting position; it neither shares the servo harness nor crosses the front axle. | The button lead follows an internal chassis route to Jetson, while preserving space to operate and service the button. |
| W5500, ESP32, and Jetson | W5500-to-ESP32 uses short Dupont wires; W5500-to-Jetson uses a downward right-angle-to-straight Ethernet cable. Customisation places the W5500 header pins and Ethernet port on opposite faces, preventing the installed connector and cable from becoming a fragile protrusion. | W5500 is fixed on a dedicated raised platform. Both Dupont and Ethernet cables follow protected internal paths while preserving space to plug and unplug the Ethernet connector. |
| Main battery to SBC/SBM | The main supply lead must carry whole-vehicle current, while branches are selected for each board's connector and installed location. | The main lead is `14 AWG` and the two branches are `18 AWG`. Flag terminals connect the plastic switch that cannot be soldered directly; the harness stays in the lower layer and cross-layer openings. Electrical distribution details are in Chapter 5. |

| Internal routing through the middle layer | Internal routing around the upper layer |
|---|---|
| Cable routing through the printed middle layer. | Cable routing around the upper-layer components. |

*Figure 12: Protected cable routes through the middle and upper chassis layers. Harnesses connect components through openings in the printed layers and internal chassis space, avoiding exposed drag points near the rear wheels.*

## Final mechanical configuration

### Chassis and layering

- The lowest layer contains the front steering module, rear drive, and low battery structure.
- The middle layer provides mounting positions for both LiDARs and cross-layer cable openings.
- The upper layer carries Jetson, ESP32, perception hardware, and protected wiring.
- Brass threaded standoffs join the printed layers; fixed holes and mounts locate the servo, motor, axle, LiDARs, and battery.

### Front axle and positive Ackermann steering

The steering chain is: SC-1258TG+ output spline → 3D-printed teardrop-shaped servo horn → ball-joint drag link → adjustable three-part tie rod → left/right steering arms → steering knuckles → front-wheel hubs.

Parallel steering could not complete the required large continuous turn reliably. The team considered reverse Ackermann geometry used by high-speed vehicles, but selected positive Ackermann for low-speed repeatable turns: the steering-arm pickup points angle inward toward the rear axle, so the inner wheel turns more sharply than the outer wheel.

### Rear drive, timing belt, and shared axle

- The GA25-370 has an integrated `9.6:1` gearbox. A `20T` driving pulley is fixed to the gearbox output shaft; when the shaft rotates, it drives the timing belt.
- Motion path: DC motor rotor → gearbox → `20T` driving pulley → timing belt → `40T` driven pulley → transverse rear axle → both rear wheels.
- The external belt reduction is `2:1`; the nominal motor-rotor-to-rear-axle reduction is `19.2:1`.
- The axle is supported by two printed mounts and brass hex hub couplers; both rear wheels have the same angular speed.
- Motor slots allow belt-tension adjustment: align pulleys, install and tension the belt, rotate by hand, lock the motor screws, then perform a powered check.

## Geometry, tyres, and mechanical-stability trade-offs

| Item | V1 | V2 | V3 / current geometric basis | Decision |
|---|---|---|---|---|
| Body length | `268 mm` | `220 mm` | `220 mm` | V2 shortened the body to reduce the swept envelope; V3 retained that length. |
| Body width | `183 mm` | `176 mm` | `120 mm` | V3 further narrowed the body to reduce lateral sweep during a turn. |
| Body height | — | `150 mm` | `158 mm` | V3 established the final height after the layered layout and equipment installation. |
| Wheelbase | `145 mm` | `138 mm` | `138 mm` | V2 shortened the wheelbase for compact turns; V3 retained it. |
| Front-wheel design angles | Inner `58°`, outer `30°` | Inner `53.7°`, outer `33.7°` | Retains the V2 positive-Ackermann front-axle layout | Maintains positive Ackermann, with a larger inner-wheel angle. |
| Wheel diameter and surface | High-friction `68 mm` commercial rear wheels | Approx. `50 mm` front / `65 mm` rear wheels | Approx. `50 mm` front / smoother `65 mm` rear wheels | V3 uses smoother rear wheels to reduce drag and occasional slip on the non-differential axle at large steering angles. |

The current body is `220 mm` long, `120 mm` wide, approximately `155 mm` wide including wheels, and has a `138 mm` wheelbase. The design target is a single continuous turn in a `375 mm` course width.

## Materials and mechanical reliability

- PLA was used for early prototypes to validate packaging, assembly order, and layer relationships.
- PA12-CF and PA6-CF were compared. The lowest and second layers use PA6-CF to carry steering, belt-drive, and repeated fastening loads.
- The upper electronics layer uses PLA so electronic boards do not directly contact conductive carbon-fibre-filled material.
- Early high-friction rear wheels caused drag. The team compared front ballast, reduced steering travel, and tyre change; the final smoother `65 mm` rear wheels were retained without front ballast.

## Iteration record

The following table connects the key mechanical iterations in their actual design order.

### Jetson/IMU Support: Height, Cooling Space, and Program-Start-Button Iteration

The early board support was `30 mm` high. The IMU, installed next to the Jetson, became very hot during operation. The team raised the support to `40 mm`, providing more air circulation around the IMU and Jetson. The early `30 mm` support STL files are [support 1](../media/stl/3d-printed-board-bracket-1.stl) and [support 2](../media/stl/3d-printed-board-bracket-2.stl); the raised `40 mm` support STL files are [Jetson support 1](../media/stl/jetson-support-1-part-1-40mm.stl) and [Jetson support 2](../media/stl/jetson-support-2-part-1-40mm.stl).

Building on the raised version, the team integrated the program-start button on the outside of the support. This allows the one permitted program-start button to be pressed from outside the vehicle after vehicle power-on, without changing the basic controller or wiring positions. The IMU's inverted installation to prevent its cable from hanging out of the rear, and its observed correct automatic-steering behaviour, are documented in [Chapter 5](05-power-and-sensor-architecture.md).

Final Jetson-support CAD with the added external program-start-button mount.

| Design theme | Iteration path and reason | Final mechanical decision |
|---|---|---|
| Steering scheme | Last year's small vehicle used parallel steering. It still required multiple forward-and-reverse adjustments to turn in the parking area; wheel angle was small and it easily contacted the boundary. The team then compared reverse and positive Ackermann: reverse Ackermann addresses high-speed cornering, while this vehicle needs stable, low-speed tight turns on a known map. | A positive-Ackermann front axle replaced parallel steering. The SC-1258TG+ drives the front wheels through a 3D-printed teardrop-shaped servo horn and servo-linkage assembly; the inner front wheel turns more than the outer wheel. |
| Chassis design: V1 → V2 → V3 | V1 measured `268 mm × 183 mm` with a `145 mm` wheelbase. To reduce the swept envelope in the `375 mm` turn space, the team first produced V2: `220 mm × 176 mm × 150 mm`, with a `138 mm` wheelbase. Retaining the V2 wheelbase and positive-Ackermann axle, the team then narrowed the body and completed the layered equipment layout. | V3 is the current version: `220 mm × 120 mm × 158 mm`, `138 mm` wheelbase, and approximately `155 mm` overall width including wheels. The bottom layer holds the front axle, battery bay, and rear axle; the middle layer mounts both LiDARs; the upper layer carries computing and sensing hardware. |
| Rear drive and rear wheels | The rules prohibit a differential-wheeled robot. With one motor driving a shared rear axle, the rear wheels create drag at large steering angles. Early high-friction `68 mm` commercial rear wheels made this more pronounced. | A GA25-370 drives the non-differential shared rear axle through a `20T:40T` timing-belt reduction. Rear wheels were changed to no-silicone, smoother `65 mm` 3D-printed wheels. Arc testing reduced drag and occasional slip to the minimum observed level, although it cannot be eliminated completely. |
| Single battery and lower battery bay | The early ESP32 and Jetson design used two batteries. Competition rules require one switch to start the whole vehicle and then a wait for the single program-start button; two batteries were unsuitable for that start arrangement. | One `12 V` battery powers both the SBC and SBM. It sits in the lower bay between the front and rear axles to keep the centre of mass low, and provides mounting and routing space for the SBC, SBM, and other upper modules. |
| LiDAR layout and chassis height | Course walls, traffic signs, and parking limits are all `100 mm` high. Both 2D LiDAR scan planes must be below `95 mm` and are actually about `85 mm`; a `20 mm` ground clearance would raise the scan plane too high. | Ground clearance was reduced to `7 mm`. Two 2D LiDARs weighing about `90 g` together are offset along the vehicle length, with the rear unit raised by a `5 mm` spacer; their ROS 2 scans are merged. |
| Jetson/IMU support and program-start button | [Early `30 mm`-high support 1](../media/stl/3d-printed-board-bracket-1.stl) and [support 2](../media/stl/3d-printed-board-bracket-2.stl) left the IMU very hot during operation. Competition also requires the one program-start button to remain operable after vehicle power-on. | The support height was raised to [new `40 mm`-high support 1](../media/stl/jetson-support-1-part-1-40mm.stl) and [support 2](../media/stl/jetson-support-2-part-1-40mm.stl), improving cooling space around the IMU and Jetson. The final support adds an external program-start-button mount. |
| Cable management | Exposed cables on the previous-year vehicle could be dragged into obstacles, while sensor, actuator, W5500, and power leads must pass through a multi-layer chassis. | Cable length is controlled from actual component locations; middle-layer openings and internal routes carry cables between layers. Cables do not extend outside the body outline and avoid the front axle, rear wheels, and timing belt. |
| Structural materials and drive durability | PLA deforms under sustained front-axle, rear-axle, and belt-area loads; the prior year's plastic gear at the motor-to-bearing connection failed repeatedly. A metal chassis would be robust but would consume too much of the `1.5 kg` mass budget. | The lowest and second layers are PA6-CF. The upper electronics layer is PLA so boards do not directly contact conductive carbon-fibre-filled material. Critical motor-to-rear-axle transmission uses metal timing pulleys. |
| Servo centre | The default servo centre did not match the installed horn centre, and the external servo resetter had insufficient power to reset it. | Python sends the default centre pulse to establish the installed servo centre. |

## Tests and results

| Test or analysis | Recorded result | Conclusion |
|---|---|---|
| Current positive-Ackermann turning behaviour | The smaller previous-year, parallel-steering car still needed multiple forward-and-reverse adjustments in the parking turn. Its front-wheel angle was small and it easily contacted boundaries. With positive Ackermann, the planner version with map memory drives through most ordinary corners continuously in one pass; the real-time LiDAR, map-free version without map memory does not yet achieve the same behaviour. | The current vehicle uses a positive-Ackermann front axle. Most continuous turns in the planner version demonstrate that the mechanical steering concept works; the map-free turning behaviour belongs to a separate control implementation. |
| V1 → V2 → V3 swept envelope and theoretical turning radius | With `30 mm` or `40 mm` clearance, V1 required `561 mm` or `581 mm` of width. The design evolved from V1 at `268 mm × 183 mm` with a `145 mm` wheelbase to V2 at `220 mm × 176 mm × 150 mm` with a `138 mm` wheelbase, then to V3 at `220 mm × 120 mm × 158 mm`. Using V3's `138 mm` wheelbase and the inner `53.7°` / outer `33.7°` front-wheel design angles gives a theoretical rear-axle-centre turning radius of approximately `154.1 mm`. | V3 both shortens the wheelbase and substantially narrows the body. The theoretical radius establishes steering geometry; whether the full vehicle passes within `375 mm` is still determined from a swept envelope including the wheels, overhangs, and outer front corner. |
| Servo-candidate specification and steering-torque calculation | At the vehicle's `4.8 V` supply, SC-1258TG+ is specified as `9.6 kgf·cm / 0.10 s/60°`; SC-1256TG is `16.0 kgf·cm / 0.18 s/60°`. The SC-1258TG+ uses `0.08 s` less per `60°`, a nominal response-time reduction of approximately `44.4%`. | SC-1258TG+ torque covers this vehicle's steering calculation, while its faster response better suits continuous corrections during low-speed turns and obstacle avoidance. |
| Rear-wheel arc driving comparison | The early high-friction commercial rear wheel produced substantial drag and occasional slip during large-angle arcs. After changing to a no-silicone, smoother `65 mm` 3D-printed rear wheel, arc driving became more stable and the effects of drag and occasional slip were reduced. | The selected rear wheel is the self-printed, smoother `65 mm` wheel. Testing reduced the effect to a minimum, though it cannot completely remove the inherent drag of a shared rear axle without a differential. |
| Rear-drive torque, speed calculation, and five straight-line vehicle tests | Design calculation for the `1.45 kg` vehicle, `65 mm` rear wheels, and `0.5 m/s²` starting acceleration gives required rear-axle torque of approximately `0.0466 N·m` (`0.48 kgf·cm`); planned average speed of `0.14 m/s` requires approximately `41.1 rpm` at the rear axle and `82.3 rpm` at gearbox output. In five `0 → 150` straight-line tests on the flat WRO mat with the competition `4500 mAh` battery, mean `10%–90%` acceleration was `0.545253 m/s²`, sample standard deviation was `0.063005 m/s²`, and mean stable speed was `0.319176 m/s`; this speed corresponds to approximately `93.8 rpm` at the rear axle and `187.6 rpm` at gearbox output. | GA25-370 with the `20T:40T` belt reduction covers low-speed starting torque and planned driving speed. Measured stable speed exceeds the planned `0.14 m/s` average, while working speed remains below the rated `500 rpm` gearbox-output speed. |
| Dual-LiDAR scan height, merged scan, and occlusion observation | Both 2D LiDAR scan planes are approximately `85 mm`, below `95 mm`, so they intersect the `100 mm` walls, traffic signs, and parking limits. After merging front and rear scans into `/scan`, the vehicle obtains the intended front-and-rear environment coverage. Current standoffs and cable looms obstruct some beams, so a few angles may have no return and can be treated as containing no wall or obstacle. | To retain scan height, ground clearance was reduced from the early `20 mm` to `7 mm`; front and rear LiDARs are offset, the rear unit is raised by a `5 mm` spacer, and scans are merged into `/scan`. Standoff and cable occlusion is a current limitation of the dual-LiDAR layout. |
| Single battery, `12 V` operation, and boost-module evaluation | The early two-battery plan was unsuitable for starting the whole vehicle through one switch. The team evaluated a `12 V → 19 V` Jetson boost module, but it added mass. The final single competition `12 V` battery has powered long vehicle runs without a power fault, and the current program runs without boost conversion. | One `12 V` battery powers both SBC and SBM, with no boost module; it sits in the lower bay between the axles. |
| Structural-material and drive-durability record | The previous year's plastic transmission gear between motor and bearing failed five times, while PLA structural parts can soften and bend with long-term use. The current upper PLA electronics layer has a slight bend without affecting operation; the lowest PA6-CF layer remains rigid. | Critical motor-to-rear-axle transmission uses metal timing pulleys; the lowest and second layers use PA6-CF and the upper electronics layer uses PLA. |

## Risks, limitations, and mitigations

| Risk or limitation | Mitigation |
|---|---|
| No differential on shared rear axle | Positive Ackermann and smoother `65 mm` rear wheels reduce turn drag. |
| Low `7 mm` clearance | Occasional ground contact can occur on the smooth fixed course; increased rear-drive output still lets the vehicle continue over it. |
| Belt tension or alignment changes | Adjust using motor slots, rotate by hand before lock-up, and check before powering. |
| Carbon-fibre-filled material can conduct | Use PA6-CF in load-bearing lower layers and PLA on the upper electronics layer. |
| Cables can be pulled by vibration, wheels, or external obstacles | Route cables through fixed mounting positions, cross-layer openings, and internal paths; keep every cable inside the body outline and clear of the front axle, rear wheels, and timing belt. |

## Evidence links

### CAD

- [Hiway complete mechanical STEP assembly (CAD model)](../media/cad/Botzill%20Autonomous%20Car%20-%20Hiway%20Mechanical%20Assembly.step.zip)

### Drawing

- [Hiway mechanical drawing PDF](../media/cad/botzill-autonomous-ackerman-car-drawing.pdf)

### STL

- [Complete vehicle STL model](../media/stl/hiway-v3-complete-vehicle.stl)
- [3D-printed lower chassis plate](../media/stl/3d-printed-lower-chassis-plate.stl)
- [3D-printed second-layer plate](../media/stl/3d-printed-second-layer-plate.stl)
- [3D-printed small second-layer plate](../media/stl/3d-printed-small-second-layer-plate.stl)
- [3D-printed third-layer plate](../media/stl/3d-printed-third-layer-plate.stl)
- [3D-printed battery plate](../media/stl/3d-printed-battery-plate.stl)
- [3D-printed Ethernet-port bracket](../media/stl/3d-printed-ethernet-port-bracket.stl)
- [3D-printed LiDAR mounting plate](../media/stl/3d-printed-lidar-mounting-plate.stl)
- [Early Jetson support 1 (30 mm high)](../media/stl/3d-printed-board-bracket-1.stl)
- [Early Jetson support 2 (30 mm high)](../media/stl/3d-printed-board-bracket-2.stl)
- [Raised Jetson support 1 (40 mm high)](../media/stl/jetson-support-1-part-1-40mm.stl)
- [Raised Jetson support 2 (40 mm high)](../media/stl/jetson-support-2-part-1-40mm.stl)
- [3D-printed teardrop servo horn](../media/stl/3d-printed-teardrop-servo-horn.stl)
- [3D-printed steering cup](../media/stl/3d-printed-steering-cup.stl)
- [3D-printed rear wheel 1](../media/stl/3d-printed-rear-wheel-1.stl)
- [3D-printed rear wheel 2](../media/stl/3d-printed-rear-wheel-2.stl)
- [Front-wheel silicone tyre shell](../media/stl/front-wheel-silicone-tire-shell.stl)

## Open items

None.

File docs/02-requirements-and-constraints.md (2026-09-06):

# Requirements and Constraints

## Purpose

Translate competition rules and project constraints into concrete requirements for the vehicle's design, perception, control, and testing.

## Summary

This chapter records the competition rules that directly shaped the vehicle: obstacle colours and passing directions, the three-minute course, the two-operation limit, size and mass limits, the prohibition of differential-drive bases and caster wheels, and required course-object colours. Together, these rules determine the camera, chassis, drive, power, and control approaches.

## Requirements or questions

1. **Red and green obstacles require different passing directions.** Green obstacles are passed on the left and red obstacles on the right. A 2D LiDAR provides distance but cannot distinguish obstacle colour, so the vehicle needs a camera to identify red and green obstacles.
2. **Each competition round lasts three minutes.** The team used this duration to estimate required average speed, starting acceleration, and the resulting drive torque, which guided motor, transmission, and wheel selection.
3. **Only two physical interactions with the vehicle are allowed during a run.** The first turns on vehicle power and the second starts the program; this creates the design requirement for a master power switch and a separate program-start button.
4. **The vehicle may not deliberately leave additional parts or irreversible marks, such as paint, on the course.** The vehicle therefore does not use common line-following modules or a strategy that leaves marks on the course.
5. **Vehicle envelope and mass are limited.** The vehicle may not exceed `300 mm × 200 mm × 300 mm` or `1.5 kg`; these limits constrain chassis dimensions, sensor count, material selection, and battery placement.
6. **A wall collision or moving an obstacle completely out of its designated position fails the round.** The vehicle must maintain obstacle-avoidance and steering accuracy around walls, traffic signs, and parking restrictions instead of relying on contact.
7. **Caster wheels, spherical casters, and ball wheels are prohibited.** Although purchased kits may be assembled for the competition, this rule excludes many off-the-shelf robot chassis that use casters.
8. **Electronic differential drive with one motor per side, such as a differential-wheeled robot, is prohibited.** This also excludes many individually driven off-the-shelf robot cars; this vehicle instead uses front-wheel steering and one motor driving a shared rear axle.
9. **Course-object colours are specified.** Red traffic signs are RGB `(238, 39, 55)`, green traffic signs are RGB `(68, 214, 44)`, and parking restrictions are magenta RGB `(255, 0, 255)`. These colours are direct inputs to camera recognition, the course model, and test-object colour settings.

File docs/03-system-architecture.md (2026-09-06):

# System Architecture

## Purpose

Explain how the vehicle organizes its mechanical, power, sensing, computing, communication, software-control, and safety interfaces as one system. This chapter records cross-subsystem connections and responsibilities; the corresponding chapters cover mechanical detail, power budget, sensor calibration, and software algorithms.

## Summary

The vehicle uses one 12 V main battery. Competition rules allow only two operations: the first operates the main power switch to power the complete vehicle; the second operates the Jetson-GPIO program-start button. The button pulls physical Jetson pin `29` low, and the `robot_autostart` service starts `planner.launch.py`, causing the vehicle to begin running. The Jetson Orin Nano Super Developer Kit performs perception, state estimation, and decision-making, while the ESP32-S3 and carrier board perform actuator-side control. Two LDROBOT STL-27L 2D LiDARs, an Intel RealSense D435f depth camera, and a TM171 IMU provide environment and vehicle-state information. The GA25-370 motor-integrated rear-axle Hall encoder provides pulses to the ESP32; the ESP32 calculates pulse counts and sends them to Jetson, which calculates the final odometry. The micro-ROS Agent on Jetson connects Jetson ROS 2 and the ESP32 micro-ROS node through the W5500 wired link: motor, steering, OLED, notification-tone, and status topics use Micro XRCE-DDS / UDP `8888`, while raw encoder odometry uses independent UDP `9999`. Jetson connects to the W5500 by Ethernet cable, and the W5500 connects to the ESP32 by Dupont jumper wires. All four Jetson USB-A ports are occupied by current peripherals, and its USB-C port is used for debug mode rather than this communication link. The vehicle does not use Wi-Fi under the competition rules.

## Contents

- [System components and responsibilities](#system-components-and-responsibilities)
- [Physical layout](#physical-layout)
  - [Layered arrangement](#layered-arrangement)
  - [Sensor placement and geometry](#sensor-placement-and-geometry)
  - [Drive, steering, and communication-module placement](#drive-steering-and-communication-module-placement)
- [Physical connections, ROS 2 topics, and data flows](#physical-connections-ros-2-topics-and-data-flows)
- [Key architecture decisions](#key-architecture-decisions)
- [Risks, limitations, and mitigations](#risks-limitations-and-mitigations)

```mermaid
flowchart LR
    BAT[12 V main battery and master switch] --> PWR[Controlled power branches]
    PWR --> JET[Jetson Orin Nano\nPerception, state estimation, and decisions]
    START[Program-start button\nJetson physical pin 29] -->|active-low robot_autostart trigger| JET
    PWR --> ESP[ESP32-S3\nActuator-side control]
    PWR --> SNS[LiDAR, depth camera, and IMU]
    SNS --> JET
    ENC[GA25-370 integrated Hall encoder] -->|Pulses| ESP
    JET --> AGENT[micro-ROS Agent\nROS 2 DDS ↔ Micro XRCE-DDS]
    AGENT <-->|Micro XRCE-DDS / UDP 8888\nEthernet cable| W5500[W5500]
    W5500 <-->|Dupont jumper wires| ESP
    ESP -->|Raw odometry\nUDP 9999| W5500
    ESP --> ACT[Drive motor and steering servo]
    ACT --> VEH[Vehicle motion]
    VEH --> SNS
    JET --- LOG[Logging and telemetry]
    ESP --- LOG
```

## System components and responsibilities

| Subsystem | Confirmed component or function | Inputs | Outputs or interfaces | Architecture rationale |
|---|---|---|---|---|
| Main power and first operation | One 12 V competition battery, main power switch, and controlled power branches | Battery energy | Computing, sensing, and control branches | The main power switch is the first permitted operation and supplies power to the complete vehicle; see Figure 3 for its physical location. |
| Program start and second operation | Jetson-GPIO program-start button and `robot_autostart` service | Button pulls Jetson physical pin `29` low | Service starts `planner.launch.py` | The program-start button is the second permitted operation and starts vehicle motion; see Figure 3 for its physical location. |
| Perception | Two STL-27L 2D LiDARs and D435f depth camera | Walls, pillars, parking area, and forward scene | Environment observations for Jetson | Scan data from the two LiDARs are merged for downstream processing; the D435f depth camera provides forward vision and depth/distance information. |
| Vehicle state | TM171 IMU and GA25-370 motor-integrated rear-axle Hall encoder | Heading/attitude and rear-axle pulses | IMU data and pulse counts sent by ESP32 | ESP32 reads and calculates encoder pulses; Jetson calculates final odometry from the received pulse counts. |
| High-level computing | Jetson Orin Nano Super Developer Kit | Sensor data, IMU data, and pulse counts sent by ESP32 | Perception, state estimation, decisions, and control requests | Separates compute-intensive perception/decisions from actuator-side control. |
| ROS communication bridge | micro-ROS Agent on Jetson and micro-ROS node on ESP32 | ROS 2 control, display, and audio topics; ESP32 status | ROS 2 topic bridge between Jetson and ESP32 | The Agent connects Jetson ROS 2 with the ESP32 micro-ROS node; ESP32 firmware then interprets each command and operates hardware. |
| Actuator-side control | ESP32-S3 and carrier board | Control requests from Jetson and integrated Hall-encoder pulses | Drive-motor and steering-servo control; pulse counts sent to Jetson | ESP32 reads and calculates encoder pulses while handling actuator-side control. |
| Between-computer communication | W5500, Jetson-W5500 Ethernet cable, and W5500-ESP32 Dupont jumper wires | Jetson and ESP32 data | Jetson connects to W5500 by Ethernet cable; W5500 connects to ESP32 by Dupont jumper wires | All four Jetson USB-A ports are occupied by current peripherals, its USB-C port is for debug mode, and competition rules do not allow Wi-Fi. |
| Actuation | Rear-drive GA25-370 motor, front SC-1258TG+ steering servo, servo-linkage assembly, and Ackermann front axle | ESP32 control outputs | Longitudinal motion and front-wheel steering | The rear-drive motor controls forward, reverse, and speed; the steering servo drives the Ackermann front axle through the servo-linkage assembly to control front-wheel steering and travel direction. |
| Recording | Jetson/ESP32 logs and telemetry | Perception, decision, and control state | Traceable debugging and test evidence | Supports fault isolation, test comparison, and pre-competition checks. |

## Physical layout

### Layered arrangement

The lowest layer holds steering, rear drive, and battery; the middle layer provides the battery bay and mounting positions for both LiDARs; the upper layer holds the ESP32, Jetson, perception hardware, and cross-layer wiring.

| Lowest layer | Middle LiDAR layer | Top deck |
|---|---|---|
| Lowest vehicle layer, including steering, rear drive, and battery position. | Middle layer with both LiDARs. | Top vehicle deck. |

*Figure 1: Layered vehicle structure. The left image shows the lowest layer; the center image shows the middle layer holding the two LiDARs; the right image shows the top deck.*

| Rear view of layers | Upper layer with ESP32 and speaker | Complete layers with Jetson |
|---|---|---|
| Rear view of the layered vehicle. | Upper layer with ESP32 and speaker. | Side view of the complete vehicle layers after Jetson installation. |

*Figure 2: Complete layered vehicle arrangement. The left image is a rear view; the center image shows the upper layer holding the ESP32 and speaker; the right image shows the complete side layering after Jetson installation.*

Top view of the upper electronics after cable routing.

*Figure 3: Wiring of the upper electronics. This image records the Jetson, ESP32, W5500, and their connected cable harnesses.*

**Main power and program start:** The main power switch performs the first operation and powers the complete vehicle. The program-start button is beside Jetson; pressing it pulls physical Jetson pin `29` low, which causes the `robot_autostart` service to launch `planner.launch.py`. Together, these are the first and second operations specified by the competition rules.

| Main power switch | Program-start button location |
|---|---|
| Vehicle main power switch. | Close-up of the blue program-start button beside Jetson. |

*Figure 4: Physical switches used for the two operations. The left image shows the main power switch; the right image shows a close-up of the blue program-start button beside Jetson.*
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

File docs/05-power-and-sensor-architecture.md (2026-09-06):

# Power and Sensor Architecture

## Purpose

Document the vehicle electrical architecture, current budget, wiring diagram, and safety measures. This chapter also records sensor selection, sensor placement and its relationship to the competition field geometry, intrinsic and extrinsic calibration, failure-point considerations, and the design iterations that led to the final system.

## Summary

The vehicle uses a two-controller electrical architecture: a Jetson SBC and an ESP32-S3 SBM. The Jetson Orin Nano Super Developer Kit is the high-level computing unit. It runs the ROS 2 perception, local localization, map/state management, and planning programs. The ESP32-S3 is the actuator-side controller. It runs micro-ROS firmware and performs low-level operation of the rear-drive motor, steering servo, Hall encoder, display, speaker, and status prompts. A micro-ROS Agent running on the Jetson connects the ROS 2 network to the ESP32 micro-ROS node over the W5500 wired Ethernet link.

One 12 V main battery, through the main power switch, powers both controller carrier boards: the Jetson uses a DC5525 input and the ESP32 driver board uses a DC5521 input. On the ESP32 carrier board, separate rails provide the 12 V motor drive, 5 V servo power, 3.3 V power for the ESP32-S3 main chip, and 5 V / 3.3 V expansion interfaces for external modules. Two LDROBOT STL-27L 2D LiDARs, an Intel RealSense D435f depth camera, and a TM171 IMU connect to the Jetson for environmental and vehicle-state sensing. The GA25-370 rear-drive motor with its built-in Hall encoder and the SC-1258TG+ steering servo connect to the ESP32 for vehicle actuation and feedback.
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

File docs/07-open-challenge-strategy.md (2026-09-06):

# Open Challenge Strategy

## An obstacle-free course: turn the route into a repeatable driving rhythm

The Open Challenge has no colour pillars or required passing manoeuvres, but it is not “drive forward on a fixed timetable.” After start, the vehicle must identify the course direction, remain in the corridor, pass four corners, maintain continuous motion from odometry and IMU, and stop only after three completed laps. The public demonstration is available on
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

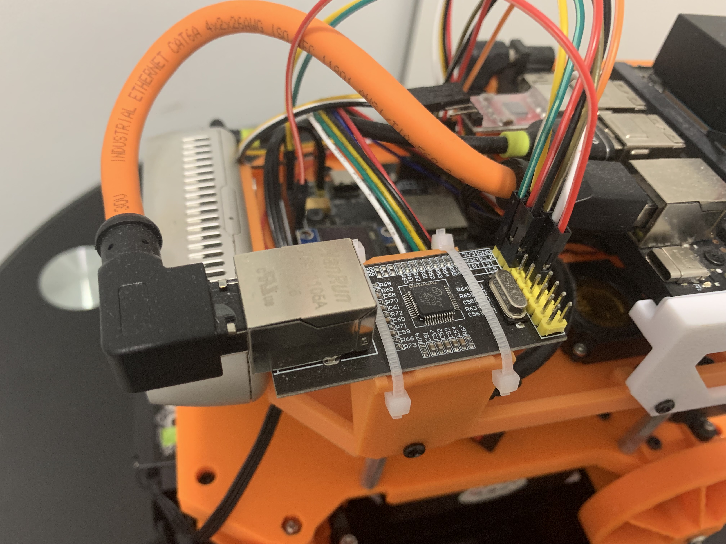
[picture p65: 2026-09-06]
media/electronics-interfaces/w5500-jetson-ethernet-esp32-dupont-overview.jpeg

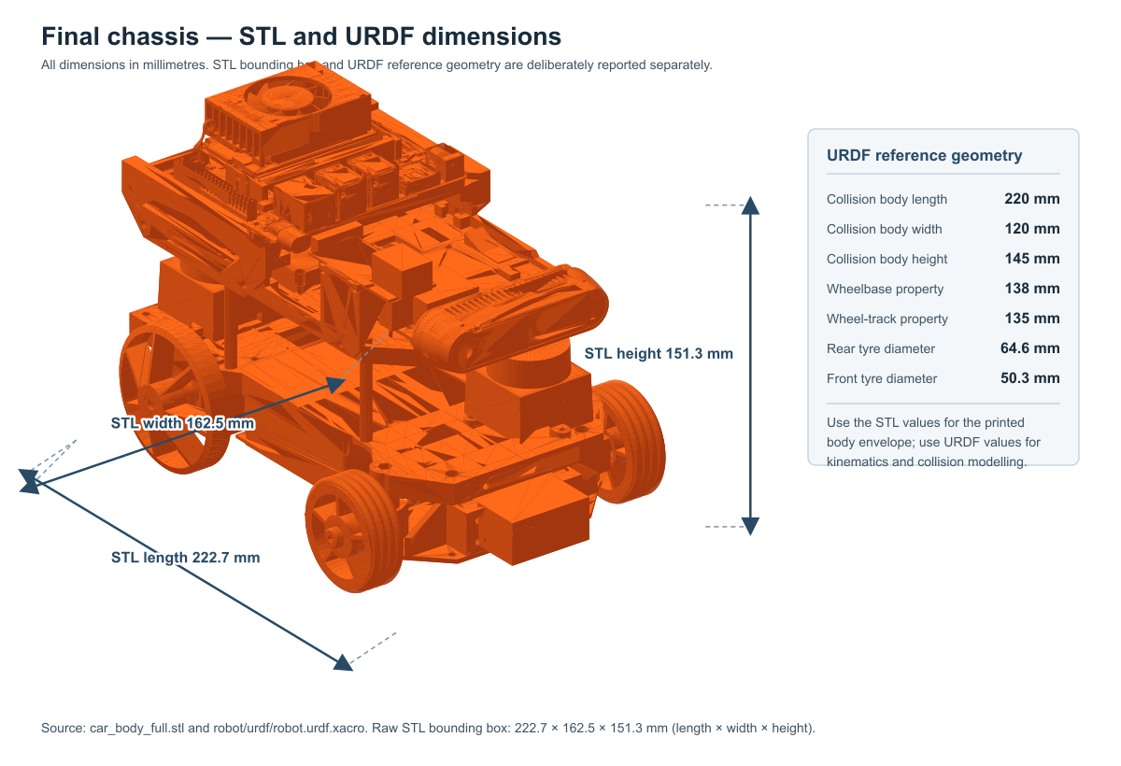
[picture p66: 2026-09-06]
media/diagrams/figure-03-final-chassis-dimensions.png

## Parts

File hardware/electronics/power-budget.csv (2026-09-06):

Branch | Component | Quantity | Rail | Operating_Power_W | Short_Peak_Power_W | Operating_12V_Equivalent_A | Short_Peak_12V_Equivalent_A | Calculation_or_Treatment
Jetson DC5525 | Jetson Orin Nano Super Developer Kit | 1 | 12 V input | 15.00 | 25.00 | 1.25 | 2.08 | 15 W operating value; 25 W upper power-mode bound
Jetson DC5525 | Intel RealSense D435f | 1 | 5 V | 2.20 | 3.50 | 0.18 | 0.29 | 0.44 A expected operating value and 0.70 A datasheet maximum
Jetson DC5525 | TM171 IMU | 1 | 5 V | 0.40 | 0.40 | 0.03 | 0.03 | 0.08 A at 5 V
Jetson DC5525 | LDROBOT STL-27L front LiDAR | 1 | 5 V | 1.45 | 2.70 | 0.12 | 0.23 | 0.29 A operating and 0.54 A startup
Jetson DC5525 | LDROBOT STL-27L rear LiDAR | 1 | 5 V | 1.45 | 2.70 | 0.12 | 0.23 | 0.29 A operating and 0.54 A startup
Jetson DC5525 | CP2102 TTL-to-USB adapter | 1 | Jetson USB 5 V |  |  |  |  | Rear LiDAR USB adapter
Jetson DC5525 | Jetson-side subtotal |  | 12 V equivalent | 20.50 | 34.30 | 1.71 | 2.86 | Operating: 15 + 2.2 + 0.4 + 1.45 + 1.45; peak uses 25 W Jetson upper bound plus 3.5 W D435f and two 2.70 W LiDAR startups
ESP32 DC5521 | ESP32-S3 and driver-board base load | 1 | board 3.3 V / 5 V | 0.60 | 0.60 | 0.05 | 0.05 | Controller base power; OLED and ES8311 control electronics included here
ESP32 DC5521 | W5500 Ethernet controller | 1 | 3.3 V | 0.42 | 0.44 | 0.04 | 0.04 | 128 mA operating and 132 mA peak at 3.3 V
ESP32 DC5521 | SC-1258TG+ steering servo | 1 | 5 V | 0.60 | 30.00 | 0.05 | 2.50 | 120 mA rated and 5 A at upper 6 V rating for brief peak
ESP32 DC5521 | GA25-370 rear drive motor and Hall encoder | 1 | 12 V | 5.00 | 5.00 | 0.42 | 0.42 | Drive load
ESP32 DC5521 | 0.96 in OLED | 1 | 3.3 V |  |  |  |  | Included in ESP32 driver-board base allowance
ESP32 DC5521 | ES8311 audio codec | 1 | board low-voltage rail |  |  |  |  | Included in ESP32 driver-board base allowance
ESP32 DC5521 | NS4150B amplifier and speaker | 1 | 5 V |  |  |  |  | Startup audio is negligible
ESP32 DC5521 | ESP32-side subtotal |  | 12 V equivalent | 6.62 | 36.04 | 0.55 | 3.00 | Operating: 0.60 + 0.42 + 0.60 + 5.0; peak: 0.60 + 0.44 + 30.0 + 5.0
Main battery | Whole-vehicle component sum |  | 12 V | 27.12 | 70.34 | 2.26 | 5.86 | Operating sum and short-peak sum before margin
Main battery | Whole-vehicle wire-sizing budget |  | 12 V |  |  | 2.26 | 7.62 | Operating component sum; 5.86 A short peak times 1.30 margin
Battery comparison | Final WHEELTEC battery | 1 | 12 V / 4.5 Ah |  |  |  |  | Nominal capacity: 4.5 Ah; nominal stored energy: 12 V times 4.5 Ah equals 54 Wh
Battery comparison | One-hour operating requirement |  | 12 V |  |  |  |  | Required energy: 27.12 Wh; required charge: 2.26 Ah; both are below nominal battery capacity
Battery comparison | Theoretical operating duration |  | 12 V |  |  |  |  | 54 Wh divided by 27.12 W equals approximately 1.99 h before losses
Battery comparison | Short-peak load |  | 12 V |  |  |  |  | Short-peak current: 7.62 A; short-peak power: 91.44 W

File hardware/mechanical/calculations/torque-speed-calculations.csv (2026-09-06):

Parameter | Symbol | Value | Unit | Source_or_basis | Formula_or_Notes
Vehicle mass | m | 1.45 | kg | Measured with competition battery | Use the final competition configuration for every verification test.
Rear tyre diameter | D | 0.065 | m | Confirmed physical measurement
Rear tyre radius | r | 0.0325 | m | Calculated | r = D / 2.
Steady speed at motor command 150 | v | 0.319176 | m/s | Five-run wheel-odometry measurement | Mean steady speed.
10-90 percent acceleration at motor command 150 | a | 0.545253 | m/s^2 | Five-run wheel-odometry measurement | Mean acceleration over each run's 10-90 percent speed rise.
10-90 percent acceleration sample SD | s_a | 0.063005 | m/s^2 | Five-run wheel-odometry measurement
Linear-fit acceleration | a_fit | 0.460465 | m/s^2 | Five-run wheel-odometry measurement | Secondary analysis over the same rise interval.
Rolling resistance coefficient | Crr | 0.03 | unitless | Calculation value | Crr = F_roll / (m * g).
Rolling resistance force | F_roll | 0.427 | N | Calculated | F_roll = Crr * m * g.
Acceleration force | F_acc | 0.7906 | N | Calculated | F_acc = m * a.
Required wheel force | F_required | 1.2174 | N | Calculated | F_required = F_acc + F_roll.
Required rear axle torque | T_axle_required | 0.0396 | N*m | Calculated | T_axle_required = F_required * r.
Belt reduction | R_belt | 2.0 | ratio | Measured pulleys | 40T / 20T.
Belt efficiency | eta_belt | 0.90 | unitless | Calculation value
Required gearbox output torque | T_gearbox_required | 0.0220 | N*m | Calculated | T_axle_required / (R_belt * eta_belt).
Motor supply version | V_motor | 12 | V | Selected GA25-370 motor version | Do not use 6 V or 24 V table values.
Motor gearbox ratio | R_internal | 9.6 | ratio | Selected motor specification | Already included in manufacturer's output torque rating.
Maximum no-load gearbox output speed | n_no_load | 625 | rpm | Selected 12 V 9.6:1 motor specification
Rated gearbox output speed | n_rated | 500 | rpm | Manufacturer data for 12 V 9.6:1 model | Rated-speed condition for the rated torque value below.
Rated gearbox output torque | T_gearbox_rated | 0.0294 | N*m | Manufacturer data converted from 0.3 kgf*cm | 0.3 * 0.09807.
Theoretical rated axle torque | T_axle_rated | 0.0529 | N*m | Calculated | T_gearbox_rated * R_belt * eta_belt.
Rated torque margin | M | 1.34 | ratio | Calculated | T_gearbox_rated / T_gearbox_required.
Motor command under test | u | 150 | command units | ESP32 firmware | Command range is 0 to 400; this is not rpm or m/s.
PWM duty at command 150 | duty | 0.375 | ratio | ESP32 firmware | duty = 150 / 400 = 3071 / 8191.

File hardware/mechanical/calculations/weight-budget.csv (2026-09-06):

Item | Subsystem | Quantity | Unit_Mass_g | Total_Mass_g | Dimensions_mm | Measured_or_Estimated | Notes
SC-1258TG+ steering servo | Actuation | 1 | 64 | 64 | 40.3 x 20.2 x 37.2 | Specified | User-provided specification.
GA25-370 DC motor | Actuation | 1 | 110 | 110 | 43 x 25 diameter | Specified | User-provided specification; 43 mm is 12 mm motor plus 31 mm gearbox length.
Intel RealSense D435f depth camera | Sensing | 1 | 80 | 80 | 90 x 25 x 25 | Specified | User-provided specification.
SYD Dynamics TM171 IMU | Sensing | 1 | 19 | 19 | 40 x 36 x 12.6 | Specified | User-provided specification.
LDROBOT STL-27L 2D LiDAR | Sensing | 2 | 46.1 | 92.2 | 54 x 46.29 x 34.80 | Specified | User-provided specification.
Jetson Orin Nano Super Developer Kit | Computing | 1 | 176 | 176 | 103 x 90.5 x 34.77 | Specified | User-provided specification.
Jetson-side 12 V battery | Power | 1 | 184 | 184 | 88.6 x 61.6 x 24 | Specified | Inventory entry; capacity intentionally not restated here because battery records require separate confirmation.
ESP32 development board | Control | 1 | 35 | 35 | 68 x 61 x 15 | Specified | User-provided specification.
0.96 in OLED | Human-machine interface | 1 | 1.29 | 1.29 | 27 x 28.5 x 12.6 | Specified | User-provided specification.
ESP32-side 12 V battery | Power | 1 | 110 | 110 |  | Specified | Inventory entry; user-provided 1800 mAh record.
Listed component total | All listed subsystems |  |  | 871.49 |  | Calculated | 64 + 110 + 80 + 19 + (2 x 46.1) + 176 + 184 + 35 + 1.29 + 110. Speaker treated as negligible; W5500 CP2102 chassis wheels transmission wiring fasteners and printed parts not included.

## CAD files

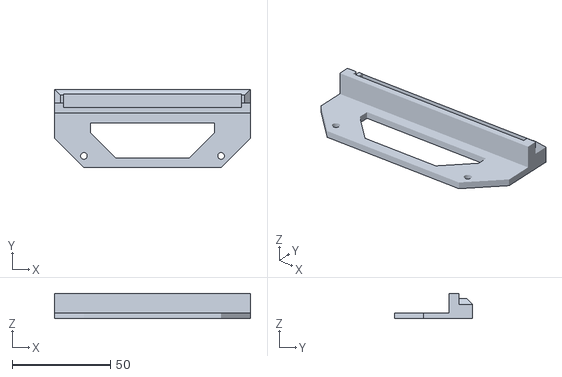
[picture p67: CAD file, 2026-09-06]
media/stl/jetson-support-1-part-1-40mm.stl
100.0 x 40.0 x 13.0

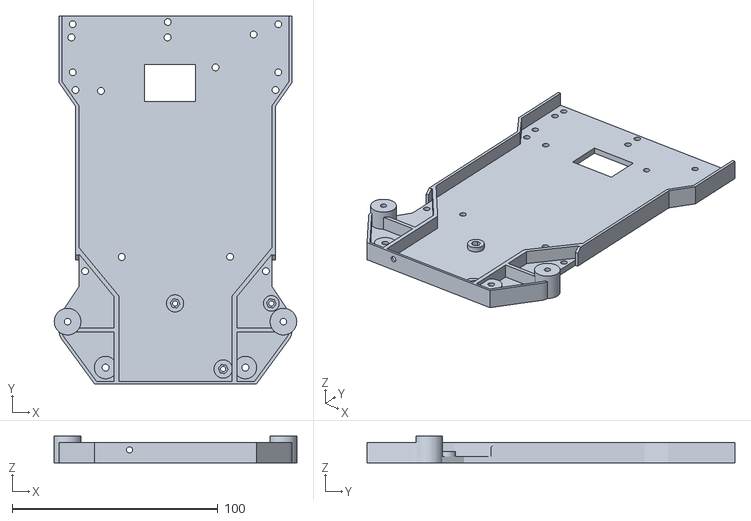
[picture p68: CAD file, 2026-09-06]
media/stl/3d-printed-second-layer-plate.stl
118.0 x 179.0 x 13.0

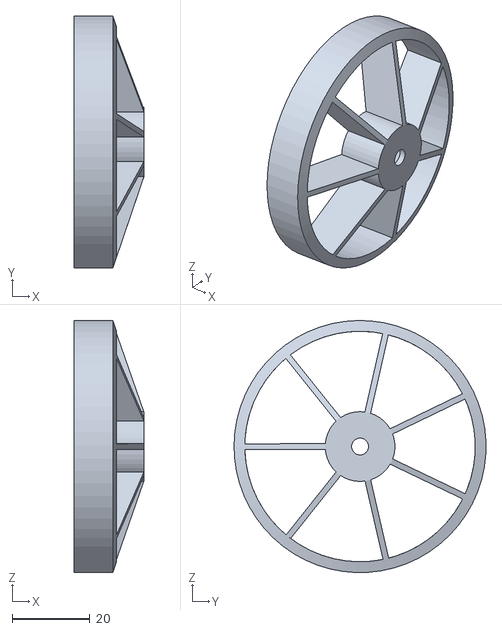
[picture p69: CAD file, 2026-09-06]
media/stl/3d-printed-rear-wheel-2.stl
18.0 x 65.0 x 65.0

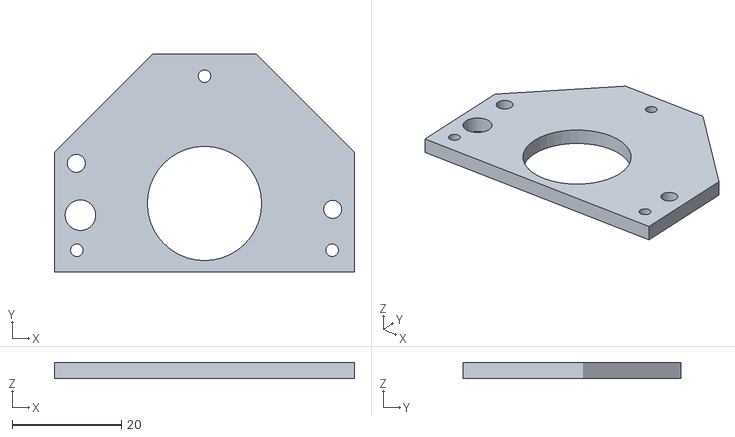
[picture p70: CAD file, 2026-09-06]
media/stl/3d-printed-lidar-mounting-plate.stl
55.0 x 40.0 x 3.00

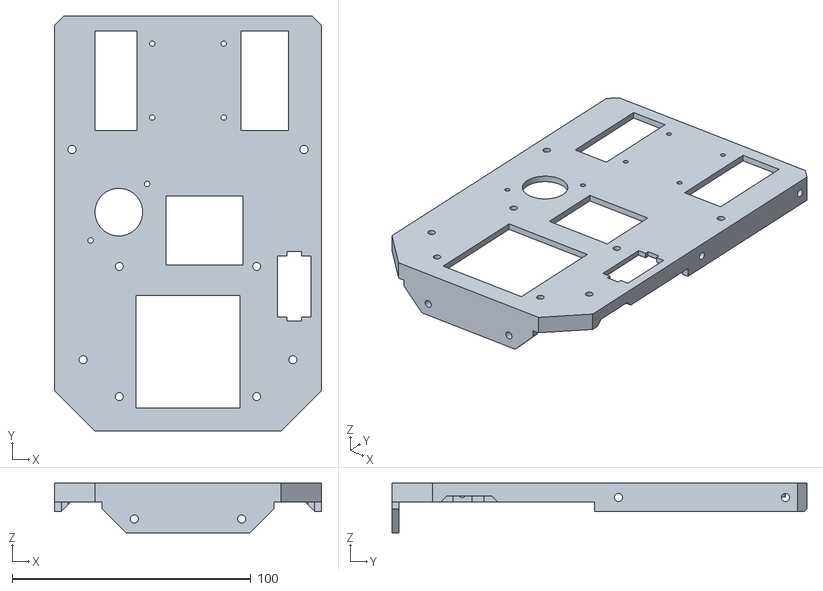
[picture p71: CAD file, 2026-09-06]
media/stl/3d-printed-third-layer-plate.stl
112.0 x 174.0 x 20.8

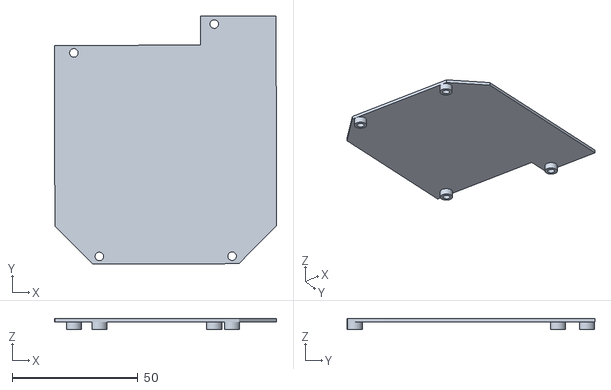
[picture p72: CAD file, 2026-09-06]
media/stl/3d-printed-battery-plate.stl
88.1 x 98.4 x 4.50

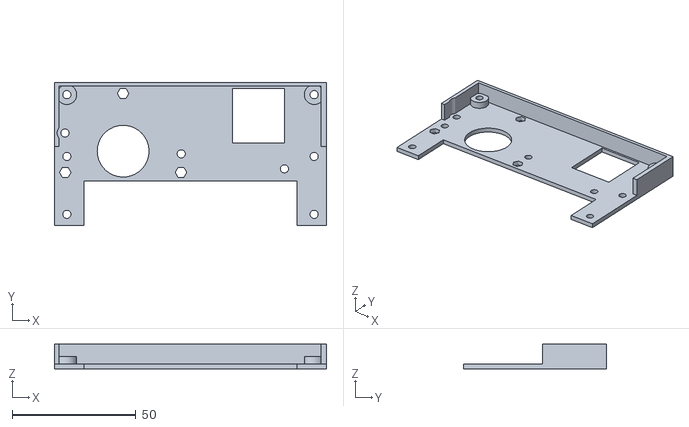
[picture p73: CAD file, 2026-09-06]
media/stl/3d-printed-small-second-layer-plate.stl
110.0 x 58.0 x 10.0

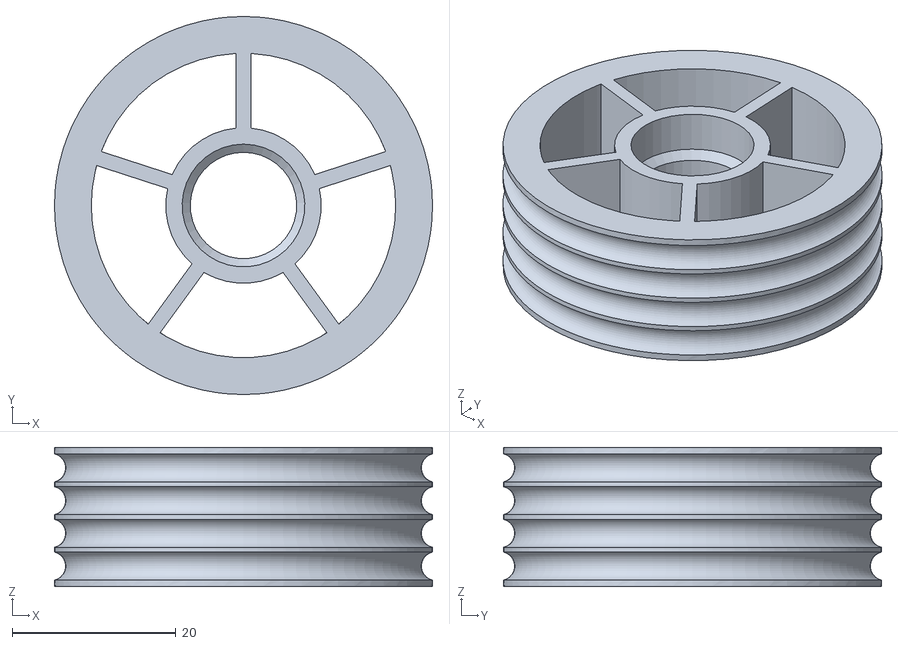
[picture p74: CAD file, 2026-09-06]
media/stl/front-wheel-silicone-tire-shell.stl
46.2 x 46.2 x 17.0

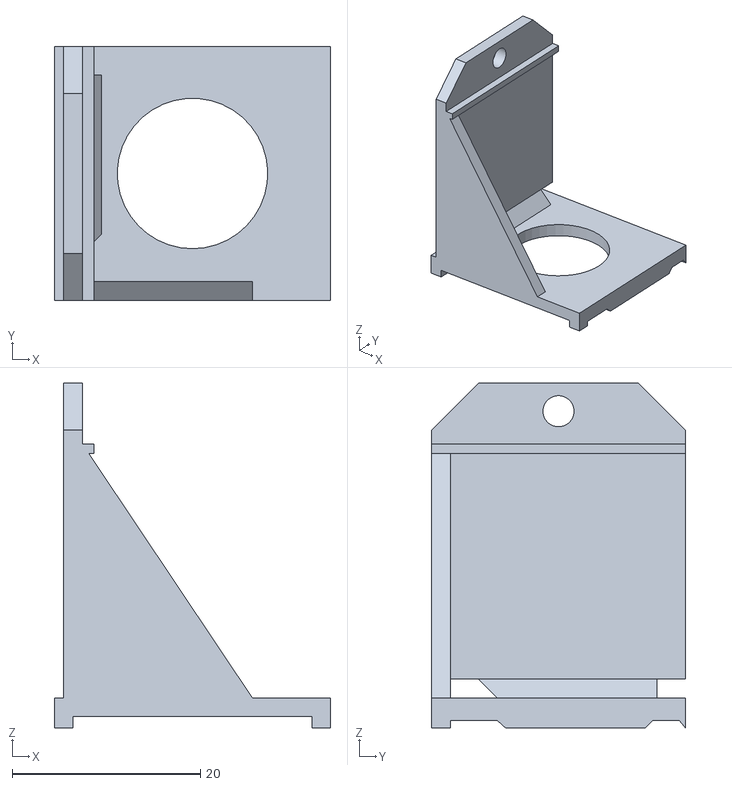
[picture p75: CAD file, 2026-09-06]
media/stl/3d-printed-ethernet-port-bracket.stl
29.4 x 27.0 x 36.7

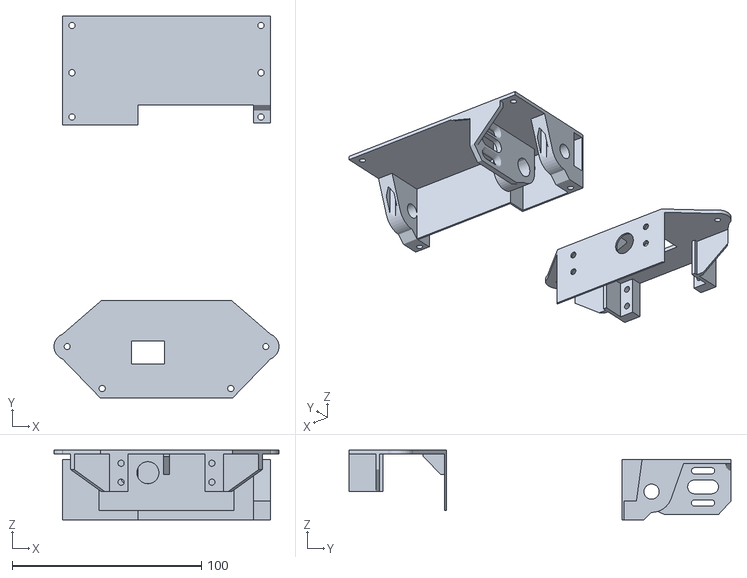
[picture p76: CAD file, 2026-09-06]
media/stl/3d-printed-lower-chassis-plate.stl
119.0 x 202.0 x 37.0

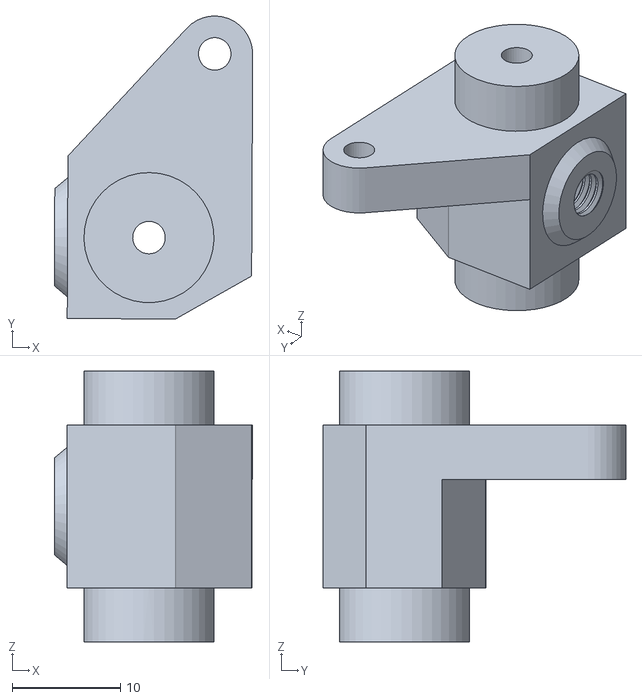
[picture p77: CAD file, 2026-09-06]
media/stl/3d-printed-steering-cup.stl
18.3 x 28.0 x 25.0

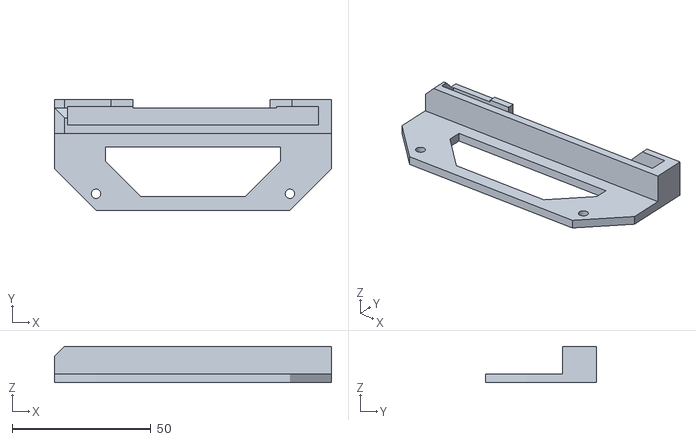
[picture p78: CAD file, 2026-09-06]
media/stl/jetson-support-2-part-1-40mm.stl
100.0 x 40.0 x 13.0

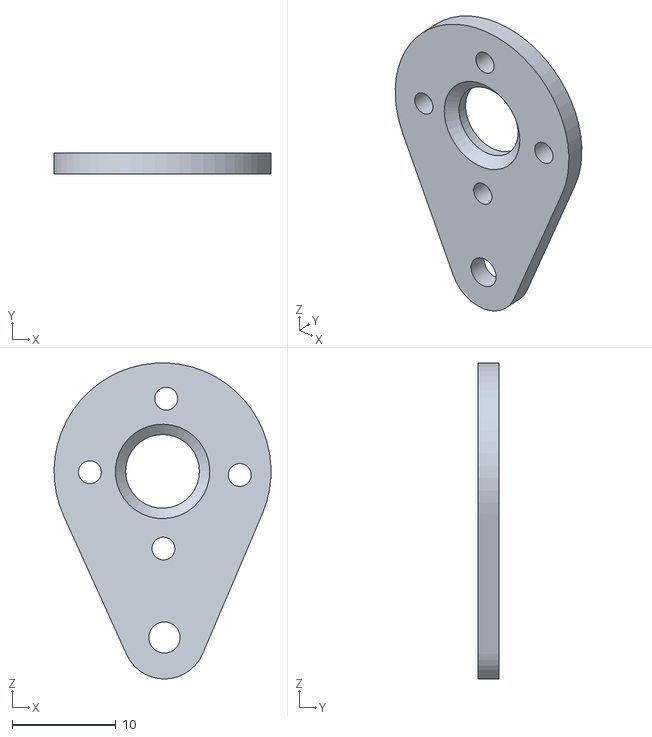
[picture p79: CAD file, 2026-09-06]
media/stl/3d-printed-teardrop-servo-horn.stl
20.9 x 2.00 x 30.4

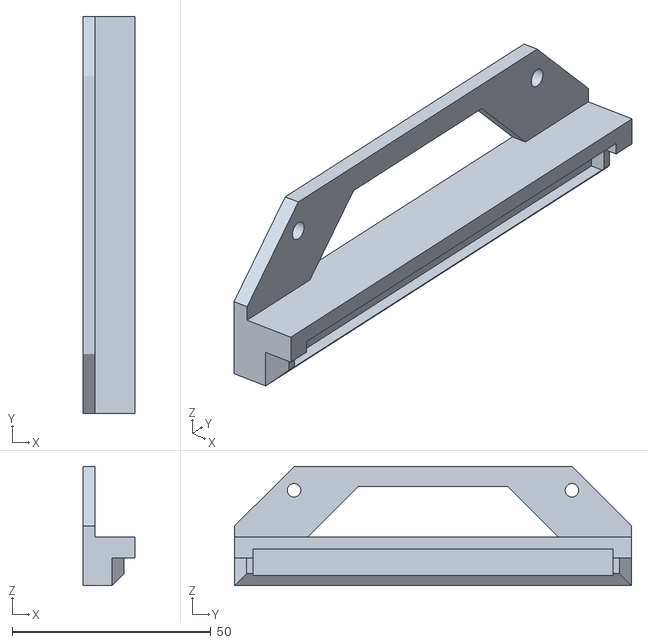
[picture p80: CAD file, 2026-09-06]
media/stl/3d-printed-board-bracket-1.stl
13.0 x 100.0 x 30.0

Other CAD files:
media/stl/3d-printed-rear-wheel-1.stl
media/stl/3d-printed-board-bracket-2.stl

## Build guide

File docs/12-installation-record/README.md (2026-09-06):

# Detailed Installation Record

This directory preserves the full step-by-step installation notes, screenshots, command history, setup alternatives, and troubleshooting observations from the vehicle build. It is intentionally separate from Chapter 12: [the chapter](../12-build-and-operation-guide.md) provides the current reconstruction and operating route, while these documents retain the detail that can be revised without compressing the historical record.

Personal user names, host names, local absolute paths, and recorded network credentials have been replaced with neutral placeholders such as `$HOME`, `<team-user>`, `<jetson-host>`, `<WIFI_SSID>`, and `<WIFI_PASSWORD>`. Replace placeholders only with the current team deployment values.

## Jetson and ROS 2

- [Jetson initial setup](001-jetson.md)
- [Install ROS 2](002-ros2.md)
- [Install base dependencies](003-base-dependency.md)
- [ESP32-S3 USB detection](004-esp32s3-usb-detect.md)
- [Ethernet, kernel modules, and user groups](008-add-module-config-eth-user-group.md)
- [VNC setup record](010-VNC.md)

## ESP32, Arduino, and micro-ROS

- [Arduino IDE and ESP32 setup](005-Arduino-01.md)
- [Arduino on Jetson](005-Arduino-Jetson.md)
- [Arduino on macOS](005-Arduino-MacBook.md)
- [micro-ROS Agent on Jetson](006-microROSAgent-Jetson.md)
- [SSH-Agent Git workflow record](007-jetson-use-mac-ssh-agent-to-push-github.md)

## Sensors, calibration, and application experiments

- [LiDAR installation and validation](009-LiDAR.md)
- [Camera SDK installation](011-Camera-SDKs.md)
- [Calibration attempt record](012-calib-no-use.md)
- [YOLO experiment record](013-YOLO-AI.md)
- [TM171 IMU installation](014-imu.md)

## Screenshot assets

All screenshots referenced by these records are stored in [images](images/). They preserve the original step context; Chapter 12 itself remains the concise, current operating guide.

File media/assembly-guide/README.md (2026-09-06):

# Assembly guide media index

This folder holds the curated build evidence for Chapter 4. It is intentionally separate from the complete `hardware-info/hardware-design-image/Images` archive: the chapter shows only the photographs needed to follow the assembly sequence, while the archive retains all development photographs.

| Build checkpoint | Files in this folder |
|---|---|
| Rear drive, belt and shared rear axle | `rear-drive-motor-pulley-bearing-assembly.jpg` |
| Front axle, servo and linkage | `front-axle-servo-linkage.jpeg` |
| Dual-LiDAR mounting | `dual-lidar-top-view.jpg` |
| Internal cable routing before and after the upper layer | `middle-layer-cable-routing.jpg`, `upper-layer-cable-routing.jpg` |
| W5500, ESP32 and Jetson connection overview | `w5500-jetson-esp32-overview.jpeg` |
| Program start button | `program-start-button-left-view.jpeg`, `program-start-button-closeup.jpeg` |

## Connection reference guides

- [Front and rear LiDAR connection guide](lidar-connection/lidar-how-to-connect.md)
- [W5500-to-ESP32 connection guide](w5500-esp32-connection/w5500-how-to-connect-esp32.md)

The two reference-guide folders include their associated close-up photographs and pin-reference images so that their Markdown links remain self-contained.

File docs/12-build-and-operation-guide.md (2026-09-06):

# Build and Operation Guide

## Purpose

Record the physical reconstruction sequence of the final vehicle. Mechanical design decisions remain in [Chapter 4](04-mobility-and-mechanical-design.md); power, interface, and sensor-cable assignments remain in [Chapter 5](05-power-and-sensor-architecture.md).

## Summary

The final vehicle is rebuilt from the lower chassis upward: prepare the wiring harnesses, assemble the steering and rear drive, install the battery compartment and LiDAR carrier, then add the upper-layer camera, controllers, network interface, and program-start button. The complete visual record is a continuous English-named archive of 108 photographs; the numbered steps below group those photographs into reconstructable operations rather than repeating every view as a separate instruction.

The [detailed installation record](12-installation-record/README.md) preserves the full setup notes, screenshots, command history, alternative host procedures, and troubleshooting records. Use this chapter as the current reconstruction and operating route; update the linked subdocuments when retaining or extending the detailed procedure.

## Mechanical Reconstruction

### Photo archive and assembly convention

The [photo manifest](../media/assembly-steps/complete-sequence/assembly-step-manifest.csv) is the machine-readable version of the complete photo record: it maps each English sequential filename (`assembly-step-001` to `assembly-step-108`) to an English description of the photographed assembly state. The complete human-readable 108-photo index is embedded below, while the [complete assembly-photo archive](../media/assembly-steps/complete-sequence/) remains the authoritative image record. Ranges in the reconstruction steps refer to the same photo numbers.

### Complete 108-photo index

Every entry below links directly to its photograph. The descriptions exactly match the English `description` field in the downloadable manifest, so the complete record can be read without opening the CSV.

| Photo | Assembly state |
|---|---|
| [001](../media/assembly-steps/complete-sequence/assembly-step-001.jpg) | All 3D-printed components before installation |
| [002](../media/assembly-steps/complete-sequence/assembly-step-002.jpg) | Fasteners, standoffs, bearings, and small joining hardware |
| [003](../media/assembly-steps/complete-sequence/assembly-step-003.jpg) | Power leads prepared for soldering |
| [004](../media/assembly-steps/complete-sequence/assembly-step-004.jpg) | Completed soldered power harness |
| [005](../media/assembly-steps/complete-sequence/assembly-step-005.jpg) | Main-power rocker switch |
| [006](../media/assembly-steps/complete-sequence/assembly-step-006.jpg) | Power harness, rocker switch, and flag terminals connected |
| [007](../media/assembly-steps/complete-sequence/assembly-step-007.jpg) | 10 cm downward-angle USB-C to straight USB-A male cable for the depth camera |
| [008](../media/assembly-steps/complete-sequence/assembly-step-008.jpg) | Superseded 30 cm ZH1.5-4P to USB-A male LiDAR cable |
| [009](../media/assembly-steps/complete-sequence/assembly-step-009.jpeg) | Final 20 cm ZH1.5 to 2.54 mm female-Dupont 1P 4-wire LiDAR harness |
| [010](../media/assembly-steps/complete-sequence/assembly-step-010.jpg) | 10 cm USB-C to USB-A male cable for the IMU |
| [011](../media/assembly-steps/complete-sequence/assembly-step-011.jpg) | 30 cm motor cable |
| [012](../media/assembly-steps/complete-sequence/assembly-step-012.jpg) | 20 cm servo cable |
| [013](../media/assembly-steps/complete-sequence/assembly-step-013.jpg) | Steering servo |
| [014](../media/assembly-steps/complete-sequence/assembly-step-014.jpg) | Drive motor |
| [015](../media/assembly-steps/complete-sequence/assembly-step-015.jpg) | Front and rear LiDAR units |
| [016](../media/assembly-steps/complete-sequence/assembly-step-016.jpg) | IMU gyroscope |
| [017](../media/assembly-steps/complete-sequence/assembly-step-017.jpg) | D435f depth camera |
| [018](../media/assembly-steps/complete-sequence/assembly-step-018.jpg) | ESP32 module and carrier board with OLED installed |
| [019](../media/assembly-steps/complete-sequence/assembly-step-019.jpg) | Jetson Orin Nano Super Developer Kit |
| [020](../media/assembly-steps/complete-sequence/assembly-step-020.jpg) | Large-capacity and small-capacity battery options |
| [021](../media/assembly-steps/complete-sequence/assembly-step-021.jpg) | 3D-printed chassis with silicone front wheels and smooth rear wheels |
| [022](../media/assembly-steps/complete-sequence/assembly-step-022.jpeg) | Front axle, servo, and Ackermann steering assembly, view 1 |
| [023](../media/assembly-steps/complete-sequence/assembly-step-023.jpeg) | Front axle, servo, and Ackermann steering assembly, view 2 |
| [024](../media/assembly-steps/complete-sequence/assembly-step-024.jpg) | Ackermann front-wheel steering knuckle |
| [025](../media/assembly-steps/complete-sequence/assembly-step-025.jpg) | Top-front oblique view of the Ackermann front axle |
| [026](../media/assembly-steps/complete-sequence/assembly-step-026.jpg) | Front view of the Ackermann front axle |
| [027](../media/assembly-steps/complete-sequence/assembly-step-027.jpg) | Rear view of the assembled Ackermann front axle |
| [028](../media/assembly-steps/complete-sequence/assembly-step-028.jpg) | Second rear view of the assembled Ackermann front axle |
| [029](../media/assembly-steps/complete-sequence/assembly-step-029.jpg) | Front view of the assembled Ackermann front axle |
| [030](../media/assembly-steps/complete-sequence/assembly-step-030.jpg) | Ackermann front axle connected to the servo, showing steering deflection |
| [031](../media/assembly-steps/complete-sequence/assembly-step-031.jpg) | Rear-axle assembly |
| [032](../media/assembly-steps/complete-sequence/assembly-step-032.jpg) | Rear-axle pulleys and shared axle |
| [033](../media/assembly-steps/complete-sequence/assembly-step-033.jpg) | Rear axle with the motor installed |
| [034](../media/assembly-steps/complete-sequence/assembly-step-034.jpg) | Rear motor and pulley detail, view 1 |
| [035](../media/assembly-steps/complete-sequence/assembly-step-035.jpg) | Rear motor and pulley detail, view 2 |
| [036](../media/assembly-steps/complete-sequence/assembly-step-036.jpg) | Custom 65 mm smooth rear wheels to reduce tyre scrub |
| [037](../media/assembly-steps/complete-sequence/assembly-step-037.jpg) | Large rear-wheel retaining nut |
| [038](../media/assembly-steps/complete-sequence/assembly-step-038.jpg) | Rear-wheel bearing |
| [039](../media/assembly-steps/complete-sequence/assembly-step-039.jpg) | Hollow metal rear-axle tube detail |
| [040](../media/assembly-steps/complete-sequence/assembly-step-040.jpg) | Top view of the open central chassis cavity before the first cover plate, view 1 |
| [041](../media/assembly-steps/complete-sequence/assembly-step-041.jpg) | Top view of the open central chassis cavity before the first cover plate, view 2 |
| [042](../media/assembly-steps/complete-sequence/assembly-step-042.jpg) | Top view of the rear chassis with battery and retaining plate, view 1 |
| [043](../media/assembly-steps/complete-sequence/assembly-step-043.jpg) | Top view of the rear chassis with battery and retaining plate, view 2 |
| [044](../media/assembly-steps/complete-sequence/assembly-step-044.jpg) | Top view after the second-layer cover plate is installed, view 1 |
| [045](../media/assembly-steps/complete-sequence/assembly-step-045.jpg) | Top view after the second-layer cover plate is installed, view 2 |
| [046](../media/assembly-steps/complete-sequence/assembly-step-046.jpg) | Second-layer front-LiDAR mounting holes |
| [047](../media/assembly-steps/complete-sequence/assembly-step-047.jpg) | Second-layer dual-LiDAR mounting: screw holes, trays, and offset mounting detail |
| [048](../media/assembly-steps/complete-sequence/assembly-step-048.jpg) | Second-layer rear-LiDAR mounting holes |
| [049](../media/assembly-steps/complete-sequence/assembly-step-049.jpg) | Top overview after LiDAR installation |
| [050](../media/assembly-steps/complete-sequence/assembly-step-050.jpg) | Front overview after LiDAR installation |
| [051](../media/assembly-steps/complete-sequence/assembly-step-051.jpg) | Rear overview after LiDAR installation |
| [052](../media/assembly-steps/complete-sequence/assembly-step-052.jpg) | Left-side overview after LiDAR installation |
| [053](../media/assembly-steps/complete-sequence/assembly-step-053.jpg) | Right-side overview after LiDAR installation |
| [054](../media/assembly-steps/complete-sequence/assembly-step-054.jpg) | Second-layer split power lead, display lead, and servo lead routed out |
| [055](../media/assembly-steps/complete-sequence/assembly-step-055.jpg) | In-progress second layer with mounted LiDARs, legacy LiDAR leads, brass standoffs, servo lead, and display cable opening |
| [056](../media/assembly-steps/complete-sequence/assembly-step-056.jpg) | Third-layer upper plate installed with two LiDAR leads and power lead routed out |
| [057](../media/assembly-steps/complete-sequence/assembly-step-057.jpg) | Third-layer upper-plate installation detail with two LiDAR leads and power lead |
| [058](../media/assembly-steps/complete-sequence/assembly-step-058.jpg) | Third-layer upper plate with motor lead routed out and second-layer tray fixed to four brass standoffs |
| [059](../media/assembly-steps/complete-sequence/assembly-step-059.jpg) | Depth-camera mounting bracket before installation, front view |
| [060](../media/assembly-steps/complete-sequence/assembly-step-060.jpg) | Depth-camera mounting bracket before installation, rear view |
| [061](../media/assembly-steps/complete-sequence/assembly-step-061.jpg) | Installing the depth camera and tightening screws |
| [062](../media/assembly-steps/complete-sequence/assembly-step-062.jpg) | Depth camera installed on the third layer |
| [063](../media/assembly-steps/complete-sequence/assembly-step-063.jpg) | ESP32 installed on the third layer |
| [064](../media/assembly-steps/complete-sequence/assembly-step-064.jpg) | ESP32 and speaker installed on the third layer |
| [065](../media/assembly-steps/complete-sequence/assembly-step-065.jpeg) | IMU cable connection before installation on the third layer |
| [066](../media/assembly-steps/complete-sequence/assembly-step-066.jpg) | IMU installed on the third layer |
| [067](../media/assembly-steps/complete-sequence/assembly-step-067.jpg) | Jetson and its two support brackets on the rear half of the third layer |
| [068](../media/assembly-steps/complete-sequence/assembly-step-068.jpg) | Combined Jetson support bracket on the third layer |
| [069](../media/assembly-steps/complete-sequence/assembly-step-069.jpg) | Jetson support bracket fixed with screws |
| [070](../media/assembly-steps/complete-sequence/assembly-step-070.jpg) | Right-side top view of the installed Jetson on the rear half of the third layer |
| [071](../media/assembly-steps/complete-sequence/assembly-step-071.jpg) | W5500 Ethernet module, tray, and cable ties |
| [072](../media/assembly-steps/complete-sequence/assembly-step-072.jpg) | Top-front view of the installed Jetson on the rear half of the third layer |
| [073](../media/assembly-steps/complete-sequence/assembly-step-073.jpg) | W5500 Ethernet module and tray secured |
| [074](../media/assembly-steps/complete-sequence/assembly-step-074.jpg) | W5500 tray installed on the third layer |
| [075](../media/assembly-steps/complete-sequence/assembly-step-075.jpg) | Top view after W5500 installation |
| [076](../media/assembly-steps/complete-sequence/assembly-step-076.jpg) | W5500 Ethernet cable connected to Jetson |
| [077](../media/assembly-steps/complete-sequence/assembly-step-077.jpg) | Servo lead connected to ESP32 on the third layer, view 1 |
| [078](../media/assembly-steps/complete-sequence/assembly-step-078.jpg) | Servo lead connected to ESP32 on the third layer, view 2 |
| [079](../media/assembly-steps/complete-sequence/assembly-step-079.jpg) | DC motor lead connected to ESP32 on the third layer, view 1 |
| [080](../media/assembly-steps/complete-sequence/assembly-step-080.jpg) | DC motor lead connected to ESP32 on the third layer, view 2 |
| [081](../media/assembly-steps/complete-sequence/assembly-step-081.jpg) | Depth camera connected to Jetson on the third layer |
| [082](../media/assembly-steps/complete-sequence/assembly-step-082.jpg) | IMU connected to Jetson on the rear half of the third layer |
| [083](../media/assembly-steps/complete-sequence/assembly-step-083.jpg) | Legacy arrangement with two LiDAR USB plugs connected to Jetson |
| [084](../media/assembly-steps/complete-sequence/assembly-step-084.jpeg) | CP2102 USB-to-TTL adapter |
| [085](../media/assembly-steps/complete-sequence/assembly-step-085.jpeg) | Front LiDAR connected to Jetson GPIO |
| [086](../media/assembly-steps/complete-sequence/assembly-step-086.jpeg) | Final rear-LiDAR TTL-to-USB connection on the second layer |
| [087](../media/assembly-steps/complete-sequence/assembly-step-087.jpeg) | Front LiDAR ZH1.5-4P connection on the second layer |
| [088](../media/assembly-steps/complete-sequence/assembly-step-088.jpeg) | ZH1.5-4P LiDAR connector insertion detail |
| [089](../media/assembly-steps/complete-sequence/assembly-step-089.jpg) | Self-soldered DC5521 power branch connected to ESP32 |
| [090](../media/assembly-steps/complete-sequence/assembly-step-090.jpg) | Self-soldered DC5525 power branch connected to Jetson, view 1 |
| [091](../media/assembly-steps/complete-sequence/assembly-step-091.jpg) | Self-soldered DC5525 power branch connected to Jetson, view 2 |
| [092](../media/assembly-steps/complete-sequence/assembly-step-092.jpg) | DC main-power switch with identification marking |
| [093](../media/assembly-steps/complete-sequence/assembly-step-093.jpg) | Installed DC power-harness switch |
| [094](../media/assembly-steps/complete-sequence/assembly-step-094.jpg) | DC power switch and flag-terminal detail, view 1 |
| [095](../media/assembly-steps/complete-sequence/assembly-step-095.jpg) | DC power switch and flag-terminal detail, view 2 |
| [096](../media/assembly-steps/complete-sequence/assembly-step-096.jpg) | Complete vehicle, top view |
| [097](../media/assembly-steps/complete-sequence/assembly-step-097.jpg) | Complete vehicle, left-side view |
| [098](../media/assembly-steps/complete-sequence/assembly-step-098.jpg) | Complete vehicle, right-side view |
| [099](../media/assembly-steps/complete-sequence/assembly-step-099.jpg) | Complete vehicle, underside view |
| [100](../media/assembly-steps/complete-sequence/assembly-step-100.jpg) | Complete vehicle, front view |
| [101](../media/assembly-steps/complete-sequence/assembly-step-101.jpg) | Complete vehicle, rear view |
| [102](../media/assembly-steps/complete-sequence/assembly-step-102.jpg) | Newly printed program-start button and its Dupont leads |
| [103](../media/assembly-steps/complete-sequence/assembly-step-103.jpeg) | Blue program-start button on the left side |
| [104](../media/assembly-steps/complete-sequence/assembly-step-104.jpeg) | Blue program-start button detail |
| [105](../media/assembly-steps/complete-sequence/assembly-step-105.jpeg) | Final vehicle, top view |
| [106](../media/assembly-steps/complete-sequence/assembly-step-106.jpeg) | Final vehicle, right-side view |
| [107](../media/assembly-steps/complete-sequence/assembly-step-107.jpeg) | Final vehicle, left-side view |
| [108](../media/assembly-steps/complete-sequence/assembly-step-108.jpeg) | Final vehicle, rear view |

### Fasteners and structural hardware

Photo 002 records the physical fasteners, standoffs, bearings, and small joining hardware used during construction. The following inventory records the supplied parts; it does not assign quantities that were not recorded.

| Hardware | Recorded specification | Assembly use |
|---|---|---|
| Cross-head self-tapping screw | 304 stainless steel, CA large flat head, `M2 × 6` | Fixes applicable 3D-printed parts. |
| Double-ended standoff | White-zinc-plated steel, `H5 × M3 × 30` | Separates and joins printed layers. |
| Cross-head round-head screw | Black, `M3 × 8` | Fixes applicable printed brackets and plates. |
| Cross-head round-head screw | Black, `M3 × 10` | Fixes applicable printed brackets and plates. |
| Cross-head round-head screw | Black, `M3 × 12` | Fixes applicable printed brackets and plates. |
| Socket-cap screw | 304 stainless steel, DIN 912, `M2 × 10` | Used at the third layer. The mechanical drawing identifies this as item 32. |
| Long threaded fastener | `M3 × 40` | Structural joining hardware supplied with the vehicle. |
| Ultra-thin flat washer | 304 stainless steel, `M6 × 8 × 0.1` | Spacing and shimming where required by the mechanical joint. |
| Deep-groove ball bearing | `696` | Rotating-joint hardware supplied with the vehicle. |

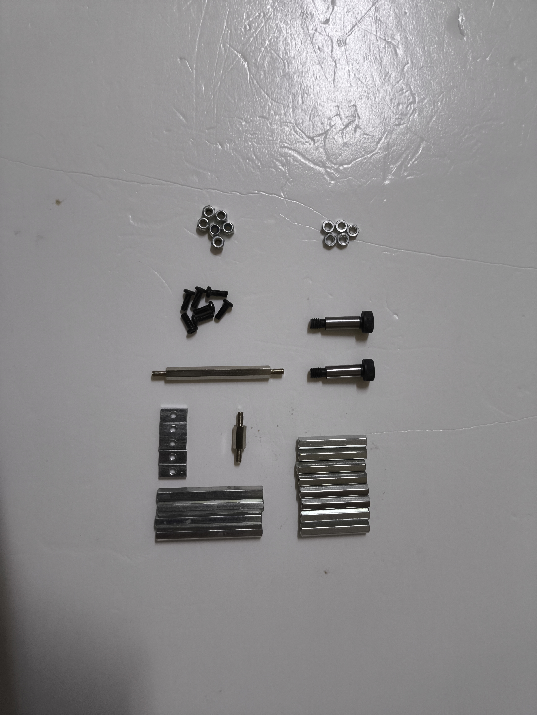
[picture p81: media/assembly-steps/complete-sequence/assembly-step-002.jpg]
Fasteners, standoffs, bearings, and joining hardware


*Figure 1. Physical fastener and joining-hardware set used for the build.*

The [mechanical drawing](../media/cad/botzill-autonomous-ackerman-car-drawing.pdf) independently calls out an `M2 × 10` screw (item 32), four `M3-45` standoffs (item 40), and `696` deep-groove bearings (item 21). The physical build inventory also contains `M3 × 40` and `H5 × M3 × 30` parts, so those fasteners must be selected by the actual mating location rather than substituted solely from the drawing. The bearing record is `696`; verify its fit to the shaft and hub before assembly.

Preview of the dimensioned mechanical drawing.

*Dimensioned mechanical-drawing preview; open the linked PDF above for the full-size drawing and item list.*

The archive records both an obsolete LiDAR lead and the final lead. Do **not** install the `30 cm` ZH1.5-4P-to-USB-A lead shown in photo 008: directly connecting it to the LiDAR did not produce a response. Use the final `20 cm` ZHR-4-to-2.54 mm female-Dupont harness shown in photo 009. Each LiDAR uses this final harness; the rear LiDAR additionally uses the `5.5 cm` CP2102 TTL-to-USB converter.

1. **Prepare the printed parts, hardware, and harnesses.** Lay out all printed components (photo 001), fasteners and brass standoffs (002), the completed main-power harness and rocker-switch/flag-terminal assembly (003–006), device cables (007–012), the actuator and sensor modules (013–020), and the wheel sets (021). Keep the `15 cm` DC5525 and DC5521 branch leads accessible before closing any chassis layer.

2. **Assemble the positive-Ackermann front axle.** Fit the SC-1258TG+ steering servo, printed servo horn, steering linkage, front knuckles, bearings, and silicone front wheels. Confirm free steering travel before closing this structure (022–030).

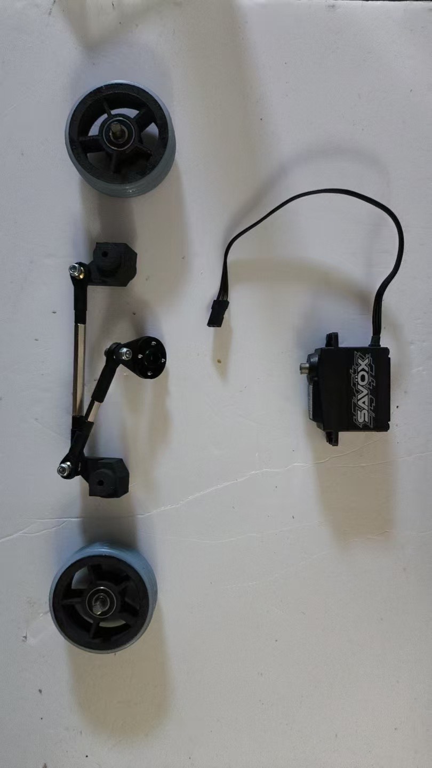
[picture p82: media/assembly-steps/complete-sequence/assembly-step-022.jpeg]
Front axle, steering linkage, servo, and front wheels before installation


*Figure 2. Front-steering parts and servo are assembled before the lower chassis is closed.*

3. **Assemble the rear drive.** Install the GA25-370 motor, `20T` drive pulley, `40T` driven pulley, timing belt, bearings, shared rear axle, and the two smooth rear wheels (031–039). Check pulley alignment and belt tension before fitting the rear drive into the lower chassis.

Rear-drive components: motor, timing belt, pulleys, shared axle, and bearings

*Figure 3. Rear-drive parts are prepared as one belt-driven shared-axle assembly.*

4. **Build the lower chassis and battery compartment.** Attach the completed front and rear assemblies to the lower chassis, install the battery and screw-fixed battery-compartment cover, then fit the next printed plate (040–045). Leave the intended openings clear for the servo, motor, power, display, and sensor cables.

5. **Install the two LiDARs on the second layer.** Fix the front and rear STL-27L units in their printed mounting positions; use the `5 mm` printed spacer at the rear-LiDAR position. The two units are intentionally offset, and the front unit is installed at `0°` while the rear unit is inverted by `180°` for the shared scan-coordinate convention (046–053).

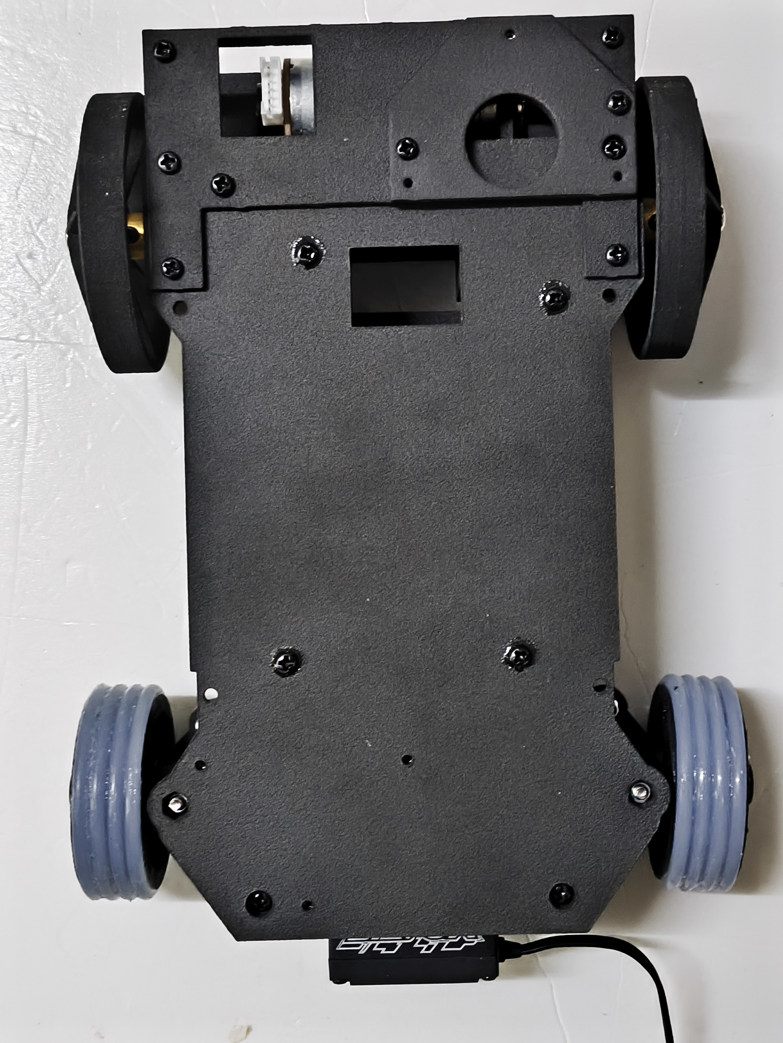
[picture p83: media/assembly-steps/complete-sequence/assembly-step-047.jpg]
Second-layer LiDAR mounting arrangement


*Figure 4. The two LiDARs use separate printed mounting positions on the second layer.*

6. **Route lower-layer cables before the third layer is fitted.** Bring the final LiDAR harnesses, the two-controller power branches, the servo lead, and the display lead through the reserved openings; route the motor lead through the rear opening. Secure the four brass standoffs and third-layer plate only after no cable crosses the steering, wheels, or timing-belt travel (054–058).

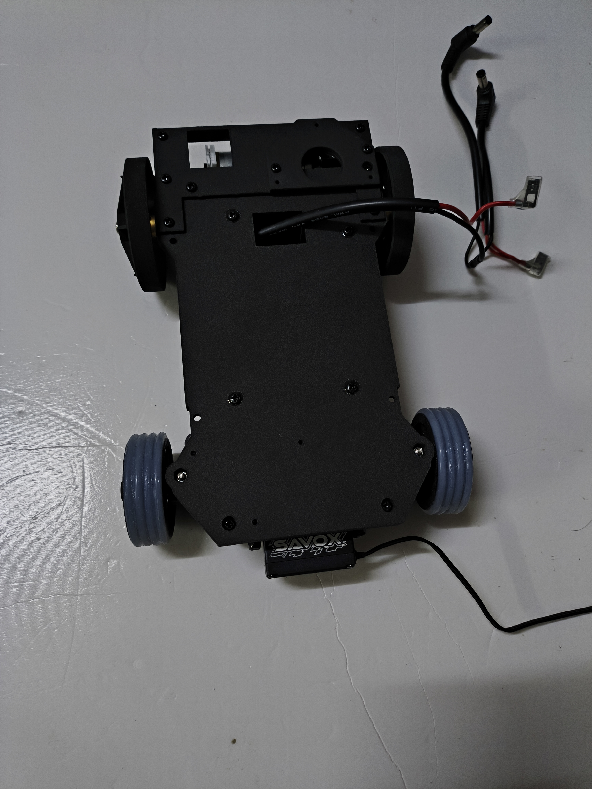
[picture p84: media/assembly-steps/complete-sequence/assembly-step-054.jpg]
Lower-layer harnesses passed through the reserved openings


*Figure 5. Cables are routed internally before the next layer blocks access.*

7. **Install the upper-layer sensing and control hardware.** Attach the D435f bracket and camera at the front centre (059–062); install the ESP32 carrier, OLED, speaker, and TM171 IMU (063–066). The IMU is installed rotated by `180°` so that its cable remains inside the body rather than trailing from the rear. Install the raised Jetson supports and Jetson Orin Nano Super Developer Kit (067–070), then mount the W5500 platform and secure the W5500 with cable ties (071–076).

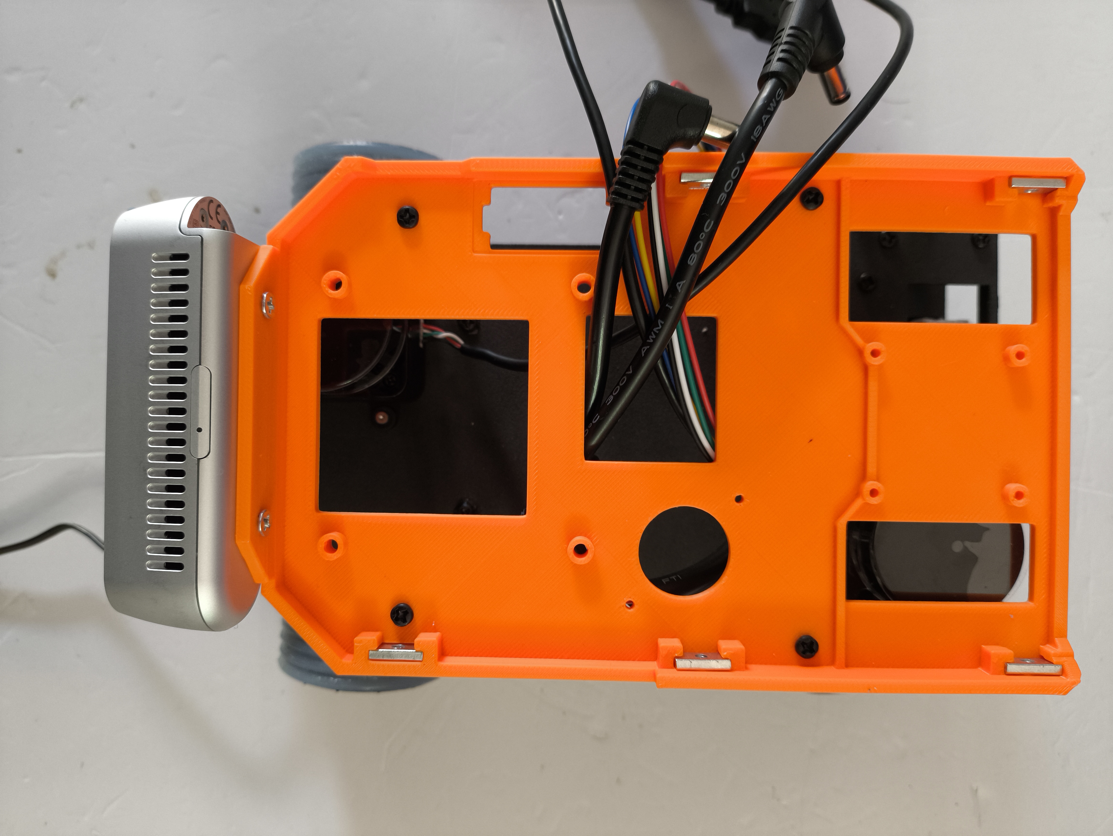
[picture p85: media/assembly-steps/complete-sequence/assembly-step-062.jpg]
Upper layer after installing the depth camera


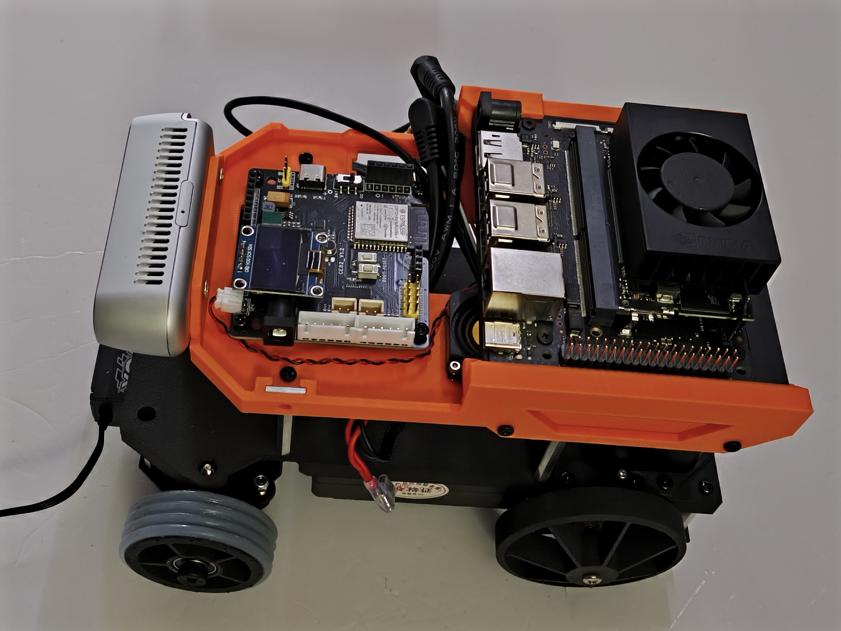
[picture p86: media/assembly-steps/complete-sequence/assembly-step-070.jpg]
Jetson installed in the raised supports


*Figure 6. The camera is added before the controller stack; the raised supports keep clearance below the Jetson.*

8. **Make the final data and actuator connections.** Connect the steering-servo and DC-motor leads to the ESP32 carrier (077–080). Connect the D435f and IMU to Jetson USB-A (081–082). Connect the front LiDAR through the Jetson 40-pin header and its final `20 cm` harness; connect the rear LiDAR through its final `20 cm` harness, `5.5 cm` CP2102 converter, and Jetson USB-A (084–088). Connect W5500 to the ESP32 with Dupont leads and to Jetson with the selected Ethernet cable (076). Detailed pin assignments and wire colours are in the [LiDAR connection guide](../media/assembly-guide/lidar-connection/lidar-how-to-connect.md) and [W5500 connection guide](../media/assembly-guide/w5500-esp32-connection/w5500-how-to-connect-esp32.md).

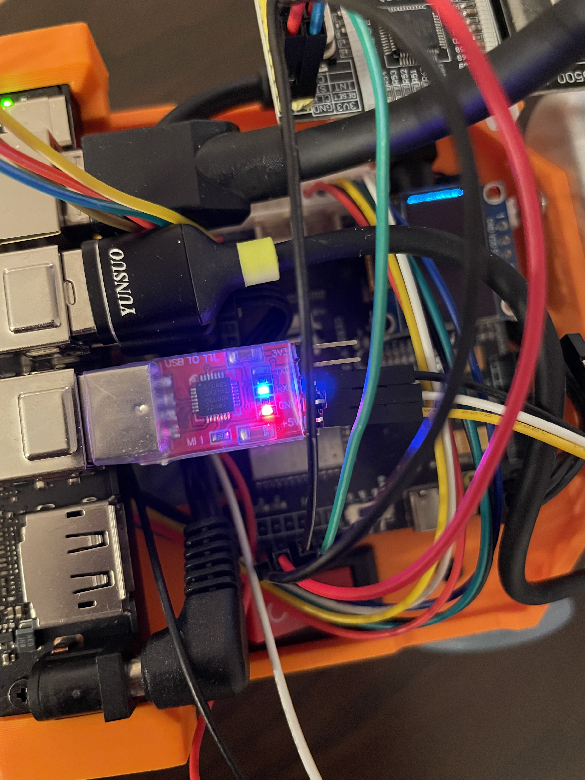
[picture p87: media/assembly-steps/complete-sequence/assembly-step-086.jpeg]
Rear LiDAR CP2102 TTL-to-USB connection


*Figure 7. The rear LiDAR requires the CP2102 conversion stage because the available GPIO UART resources are insufficient for both LiDARs.*

9. **Connect the vehicle power harness.** Connect the DC5521 branch to the ESP32 carrier and the DC5525 branch to Jetson (089–091). Install the rocker switch and flag-terminal transition (092–095). The switch is plastic and cannot be soldered directly; the flag terminals connect it to the soldered main harness.

Installed rocker switch and power-harness transition

*Figure 8. The main-power switch is installed as a removable flag-terminal transition.*

10. **Install the program-start button and perform final inspection.** Fit the separate blue program-start button and its Dupont leads (102–104). Inspect the complete vehicle from top, left, right, underside, front, and rear (096–101), then check the final assembled views (105–108). Verify that all wiring remains inside the vehicle and that no cable can contact an obstacle, the rear wheels, the timing belt, or the front steering mechanism.

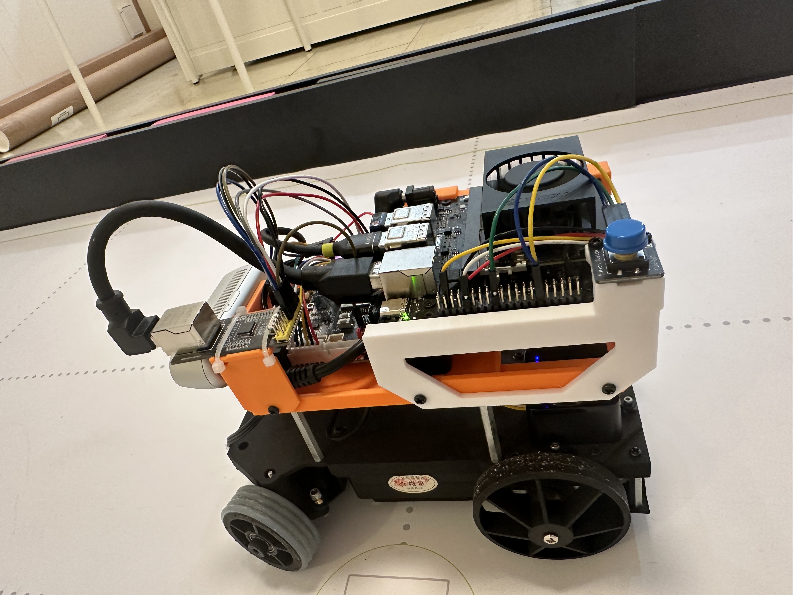
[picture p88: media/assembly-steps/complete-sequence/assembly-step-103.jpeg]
Program-start button on the vehicle left side


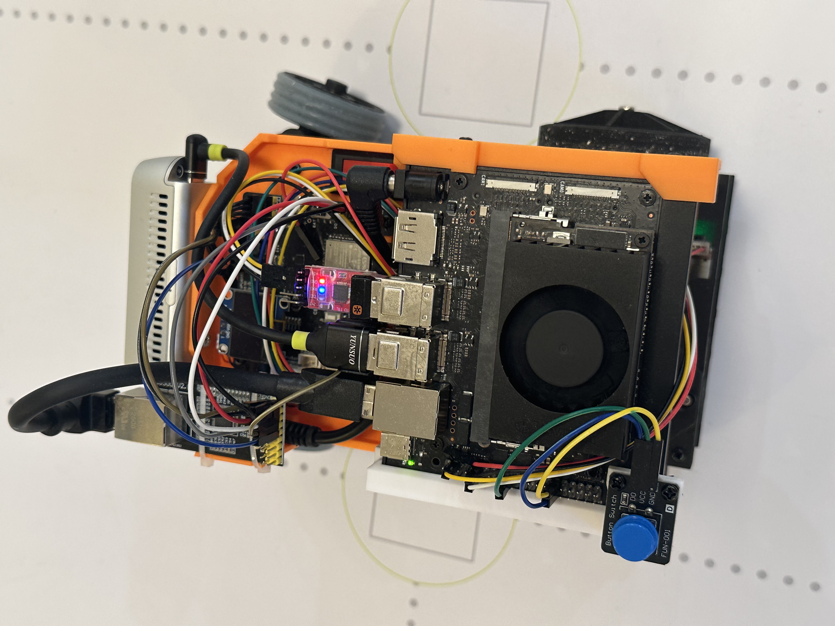
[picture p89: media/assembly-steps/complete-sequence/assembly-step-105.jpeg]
Final assembled vehicle


*Figure 9. The external start button is separate from the main power switch and is accessible after the vehicle has been assembled.*

## System Installation and Initialisation

> [!IMPORTANT]
> **Step-by-step installation records, screenshots, and troubleshooting:** [open the detailed installation record](12-installation-record/README.md). It links directly to the procedures for [Jetson initial setup](12-installation-record/001-jetson.md), [ROS 2 installation](12-installation-record/002-ros2.md), [LiDAR](12-installation-record/009-LiDAR.md), [camera SDKs](12-installation-record/011-Camera-SDKs.md), [TM171 IMU](12-installation-record/014-imu.md), and the [micro-ROS Agent](12-installation-record/006-microROSAgent-Jetson.md).

All commands in this section are deliberately user-neutral: use `$HOME`, `$USER`, detected device names, and the local network values for the deployment. Do not embed a personal username, hostname, password, or absolute home-directory path in the vehicle image, firmware, launch files, or documentation.

### 1. Prepare the Jetson system

1. Flash the NVIDIA JetPack 6 image for the Jetson Orin Nano Developer Kit to the microSD card with Balena Etcher, then boot the assembled vehicle with a display, keyboard, and mouse connected for the first setup.
2. Complete the Ubuntu initial setup, create a team-controlled account and device hostname, connect to the required network, then update and reboot:

   ```bash
   sudo apt update
   sudo apt full-upgrade -y
   sudo reboot
   ```

3. Install the build and device tools used by the ROS 2 workspaces:

   ```bash
   sudo apt install -y build-essential git wget flex bison gperf python3 python3-pip \
     python3-venv cmake ninja-build ccache libffi-dev libssl-dev dfu-util \
     libusb-1.0-0 python3-rosdep python3-colcon-common-extensions python3-vcstool
   ```

4. The NVMe SSD is used as the data volume and Docker storage. It is not the boot device. Configure it only after the system is stable on the microSD card.

### 2. Install and verify ROS 2 Humble

Install ROS 2 Humble using the Ubuntu package procedure, then source it in every shell that builds or runs ROS packages:

```bash
sudo apt install -y software-properties-common curl locales
sudo add-apt-repository universe
sudo apt update
sudo apt install -y ros-humble-desktop
source /opt/ros/humble/setup.bash
```

Verify the installation with the standard listener and talker in separate terminals:

```bash
ros2 run demo_nodes_py listener
ros2 run demo_nodes_cpp talker
```

### 3. Enable serial and Ethernet access

The rear LiDAR uses a CP2102 serial-to-USB adapter and the IMU exposes a USB serial interface. Ensure their kernel modules are loaded at boot and grant serial access to the operating user:

```bash
printf 'cp210x\ncdc_acm\n' | sudo tee -a /etc/modules
sudo usermod -a -G dialout "$USER"
```

Log out and back in after the group change. Detect device names rather than assuming a fixed port:

```bash
lsusb
dmesg | grep -E 'tty(USB|ACM)'
ls -l /dev/serial/by-id
```

Configure the Ethernet interface connected to W5500 with a static address in the same subnet as the ESP32 transport. Replace both placeholders with the detected interface and deployment address:

```bash
sudo nmcli con add type ethernet ifname <ETHERNET_DEVICE> con-name w5500-static \
  ipv4.method manual ipv4.addresses <AGENT_IP>/24
sudo nmcli con up w5500-static
```

### 4. Install sensor workspaces and validate each device

| Device | Installation and configuration | Validation |
|---|---|---|
| D435f depth camera | Install `librealsense2-utils`, `librealsense2-dev`, and `ros-humble-realsense2-*`. | Run `realsense-viewer`, then launch `realsense2_camera`. |
| Front and rear STL-27L LiDARs | Build the ROS 2 LiDAR driver workspace with submodules initialised; source ROS 2 and the workspace before launch. | Launch `viewer_lidar1.launch.py` and `viewer_lidar2.launch.py` separately; verify `/lidar1/scan` and `/lidar2/scan` in RViz2. |
| TM171 IMU | Build the project-maintained `tm_imu` package. Set `imu_port` to the detected IMU serial device, `imu_baudrate` to `115200`, `parent_frame_id` to `imu_link`, and `timer_period` to `30`. | Launch `imu.launch.py`; check `/imu_data`, `/imu_data_rpy`, `/imu_data_mag`, and `/tf`. |

Example camera installation:

```bash
sudo apt install -y librealsense2-utils librealsense2-dev 'ros-humble-realsense2-*'
ros2 launch realsense2_camera rs_launch.py
```

For each colcon workspace, use the same build pattern:

```bash
source /opt/ros/humble/setup.bash
cd "$HOME/<workspace>"
colcon build
source install/setup.bash
```

### 5. Install the ESP32 firmware toolchain and micro-ROS Agent

On the computer used to flash the controller, install Arduino IDE, the `esp32 by Espressif Systems` board package (`3.3.4`), `micro_ros_arduino` `v2.0.8-humble`, U8g2 (`2.35.30`), and the Arduino audio-driver library. Select the ESP32-S3 board and the detected serial port. Choose a sufficiently large application partition, such as **Minimal SPIFFS (1.9 MB APP)** or **Huge APP (3 MB No OTA)**, before compiling and flashing the project firmware.

Set the firmware transport to the deployed network and micro-ROS Agent address without storing credentials in this document. After flashing, press the ESP32 reset button if required to start the new firmware.

Create and build the Agent workspace on Jetson:

```bash
mkdir -p "$HOME/microros_ws/src"
cd "$HOME/microros_ws"
git clone -b humble https://github.com/micro-ROS/micro_ros_setup.git src/micro_ros_setup
sudo rosdep init
rosdep update
rosdep install --from-paths src --ignore-src -y
colcon build
source install/local_setup.bash
ros2 run micro_ros_setup create_agent_ws.sh
ros2 run micro_ros_setup build_agent.sh
source install/local_setup.bash
```

If the build reports `AttributeError: module 'em' has no attribute 'BUFFERED_OPT'`, use the recorded compatible version before rebuilding:

```bash
python3 -m pip install 'empy==3.3.4'
```

Start the Agent on the W5500 network path:

```bash
export ROS_DOMAIN_ID=30
export XRCE_DOMAIN_ID_OVERRIDE=30
source /opt/ros/humble/setup.bash
source "$HOME/microros_ws/install/local_setup.bash"
ros2 run micro_ros_agent micro_ros_agent udp4 --port 8888
```

### 6. Initialisation and pre-run checks

After the main power switch is on, start the micro-ROS Agent and confirm that the ESP32 topics appear before beginning the autonomous stack. Check the following in order:

```bash
ros2 topic list
ros2 topic echo /microROS/status
```

- Confirm `/microROS/motor_control`, `/microROS/servo_control`, `/microROS/encoder_data`, `/microROS/oled_display`, `/microROS/audio_play`, and `/microROS/status` are available.
- Check camera, both LiDARs, and IMU independently before launching their fusion or navigation processes.
- Verify the OLED status stream reports the battery value; its low-battery alert is part of the vehicle safety check.
- Confirm the motor is stopped and the steering linkage is unobstructed before pressing the separate program-start button.

## Evidence links

- [Complete English-named assembly-photo manifest](../media/assembly-steps/complete-sequence/assembly-step-manifest.csv)
- [Mechanical design, CAD, and STL evidence](04-mobility-and-mechanical-design.md#evidence-links)
- [Power-harness, interface, and sensor wiring evidence](05-power-and-sensor-architecture.md)
- [Curated assembly-guide index](../media/assembly-guide/README.md)

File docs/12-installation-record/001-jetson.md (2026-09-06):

# Jetson initial setup

## Ref document link here:
https://www.jetson-ai-lab.com/initial_setup_jon.html#

## Ref video link here:
https://www.youtube.com/watch?v=-PjMC0gyH9s&t=258s

## Prerequisite:
1. 256G microSD
2. parriot NVMe Gen3 256g
3. car reader
4. Monitor
5. keyboard and mouse (USB)
6. DisplayPort to HDMI(Or DVI) or any ports fit for your Monitor

**You may begin directly from the following section and omit the preceding content.**
Firmware 36.x

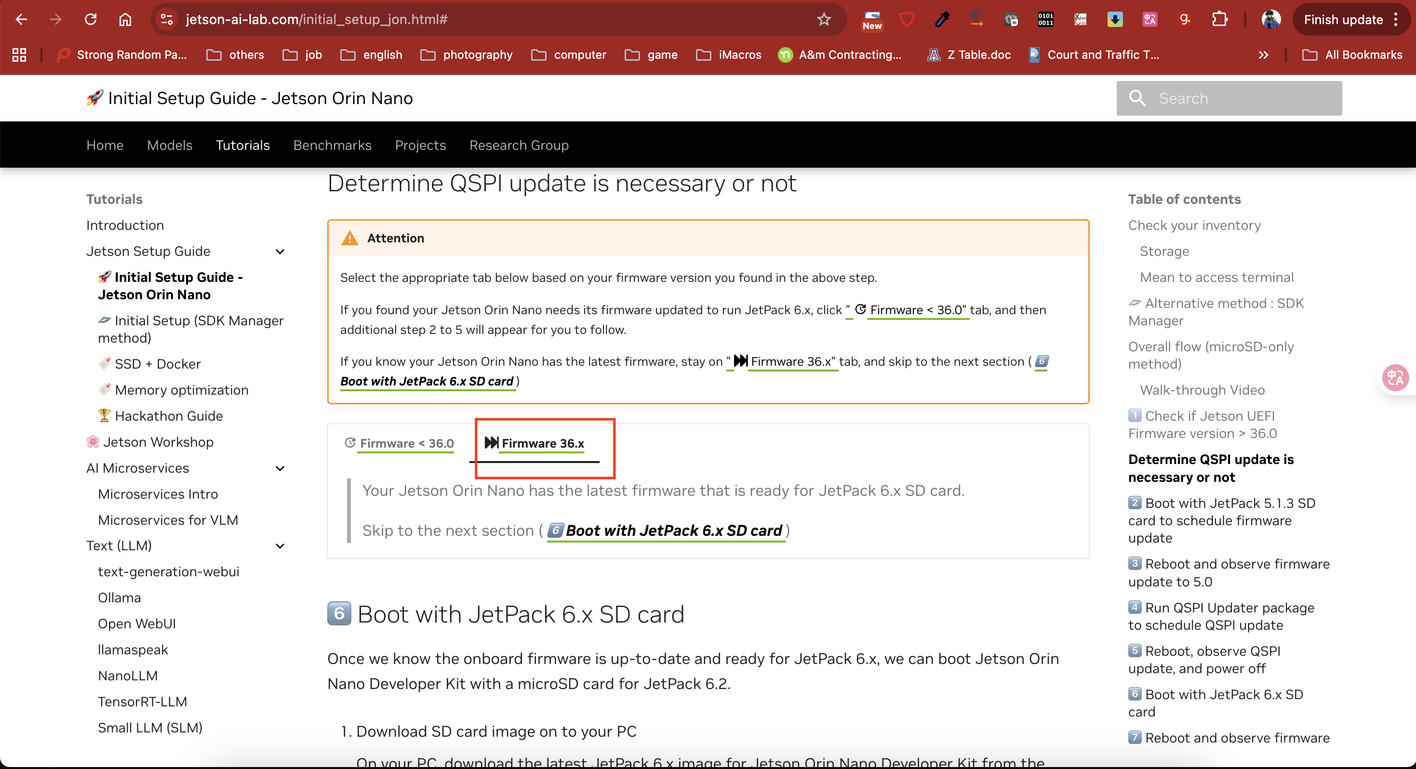
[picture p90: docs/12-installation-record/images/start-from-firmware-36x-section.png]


## Download jetson jetpack package
Jetson Orin Nano Developer Kit

JetPack 6.

10.88G

Extracting it...

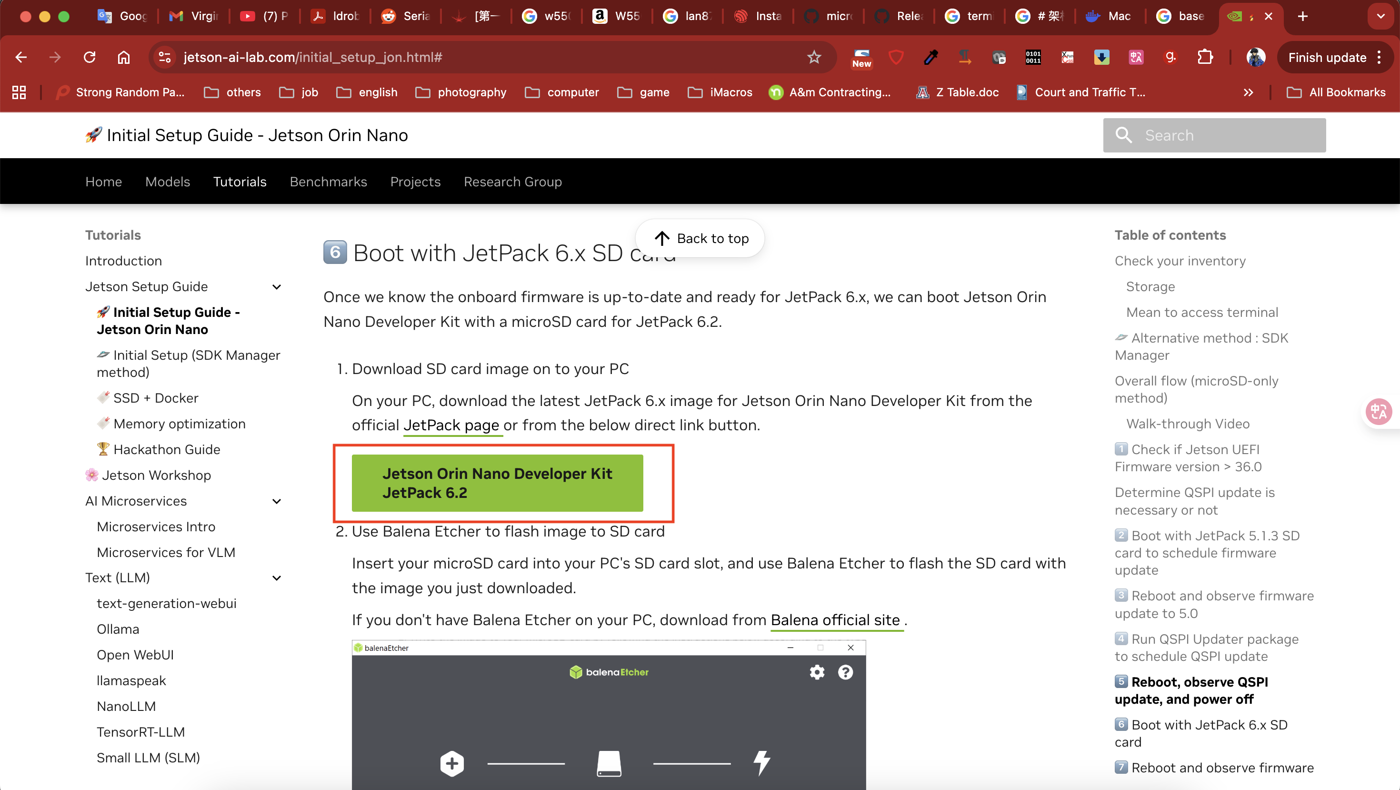
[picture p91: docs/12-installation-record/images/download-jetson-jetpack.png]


## Install Balena Etcher

https://etcher.balena.io/

Install and Open

## Use Balena Etcher to flash jetpack image to SD card

Selct "Flash from file" - sb-blob.img

Select target "<your 256G microSD>"

Click "Flash!"

Until you see "Flash Completed!"

Close Balena Etcher

Eject "microSD and card reader"

## Jetson hardware connect

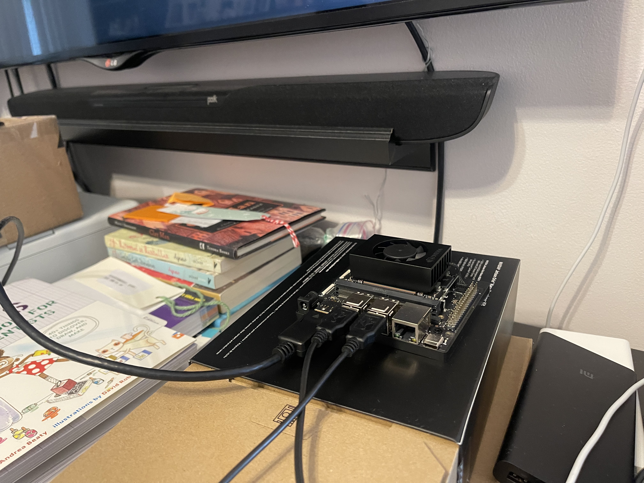
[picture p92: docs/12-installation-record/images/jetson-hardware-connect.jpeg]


jetson connect to display and usb keyboard mounse

Display Port connect to Monitor / Display

USB port connect to Keyboard / Mouse

## Jetson GUI install

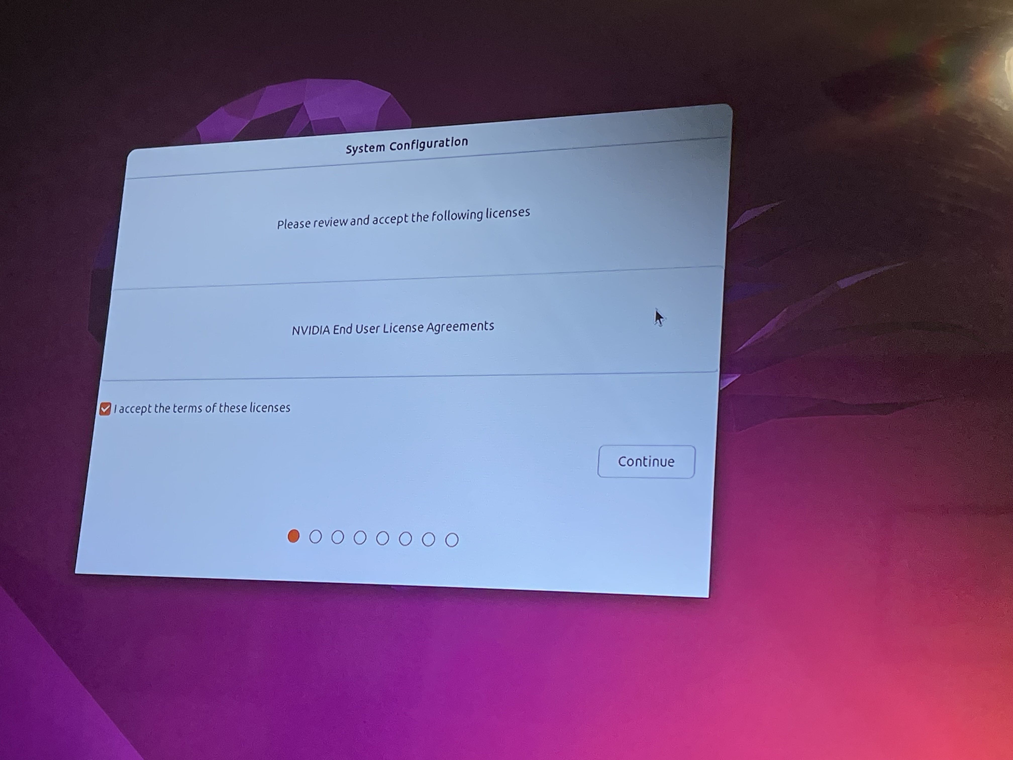
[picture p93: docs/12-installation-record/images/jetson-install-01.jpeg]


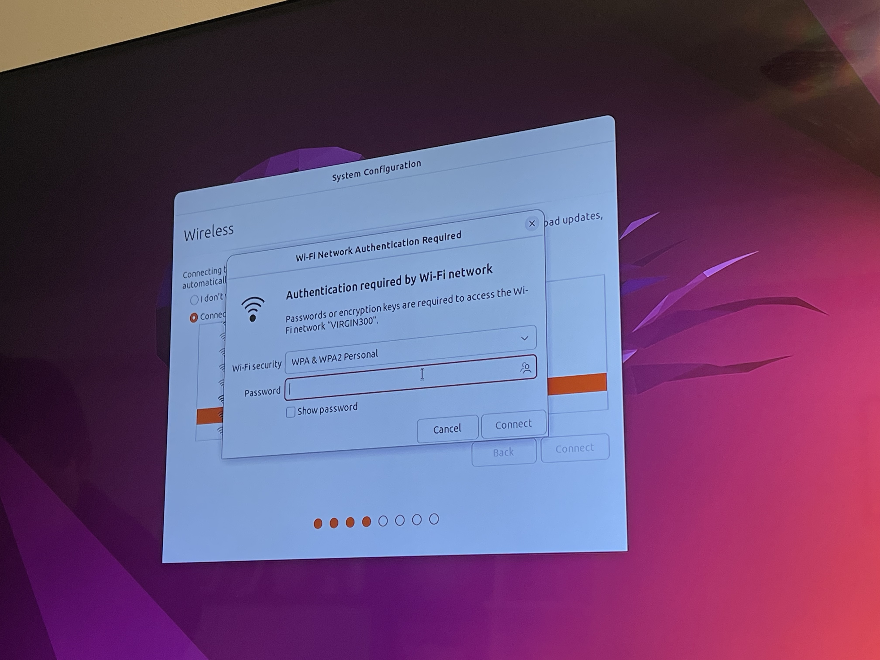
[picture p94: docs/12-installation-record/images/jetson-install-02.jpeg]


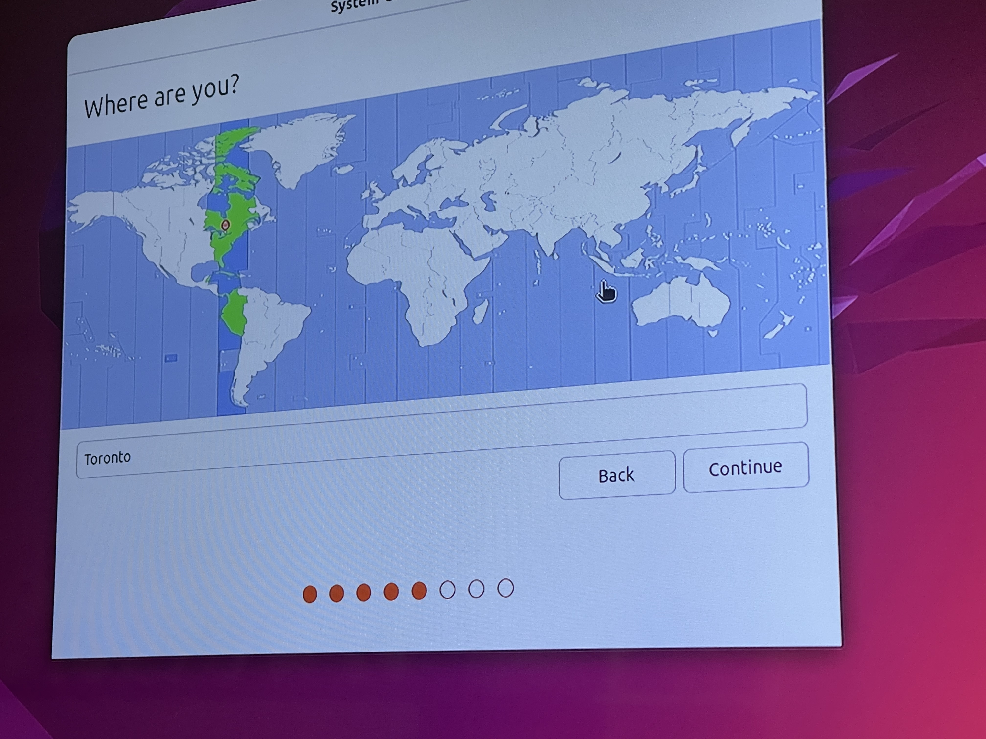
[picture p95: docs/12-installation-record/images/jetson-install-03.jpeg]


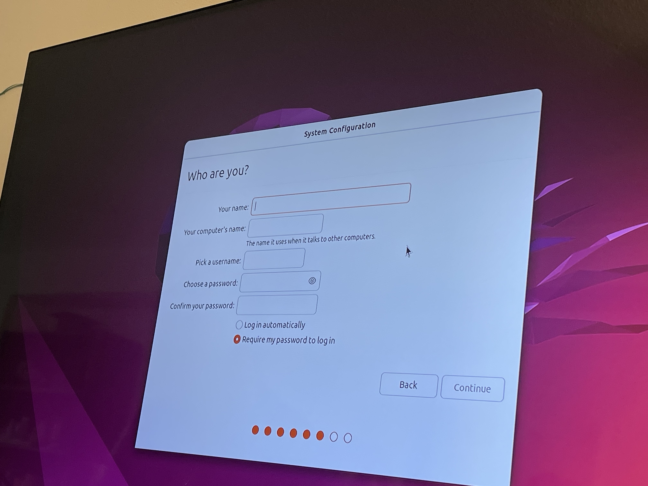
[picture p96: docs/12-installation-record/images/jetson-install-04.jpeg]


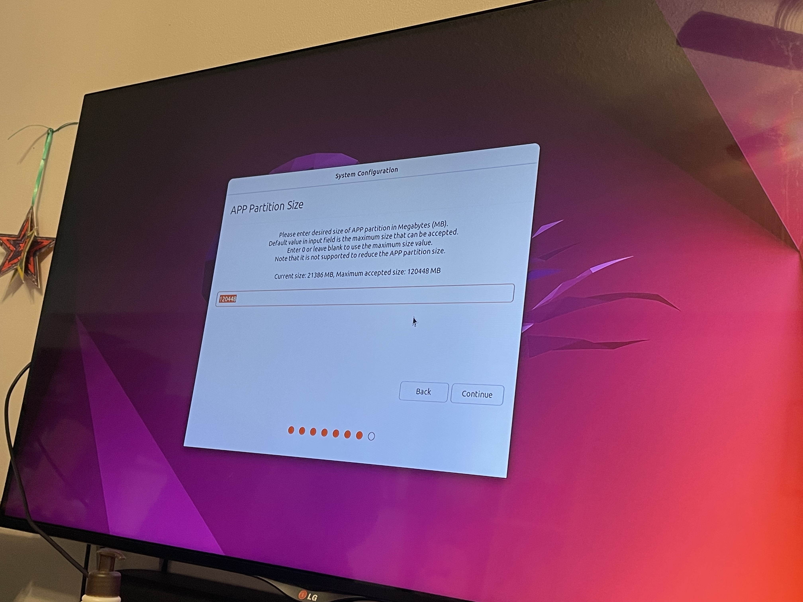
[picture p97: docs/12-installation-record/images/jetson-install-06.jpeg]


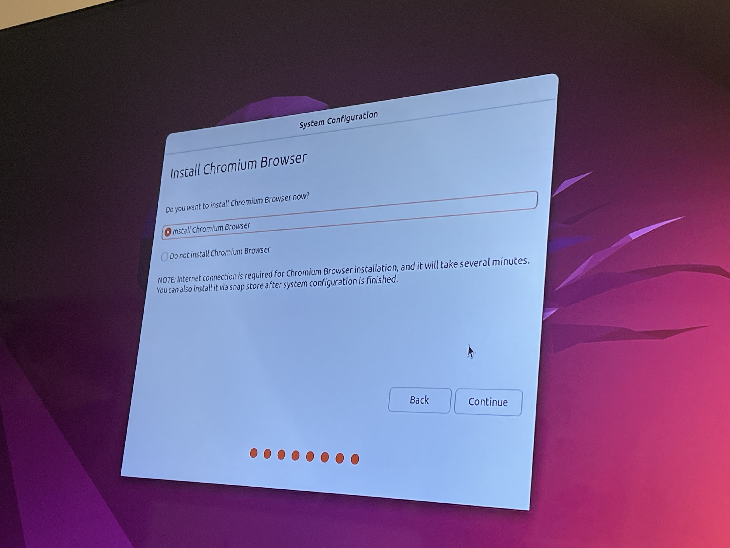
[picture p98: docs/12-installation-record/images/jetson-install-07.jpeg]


**you may facing chrome not able to install issue at here**

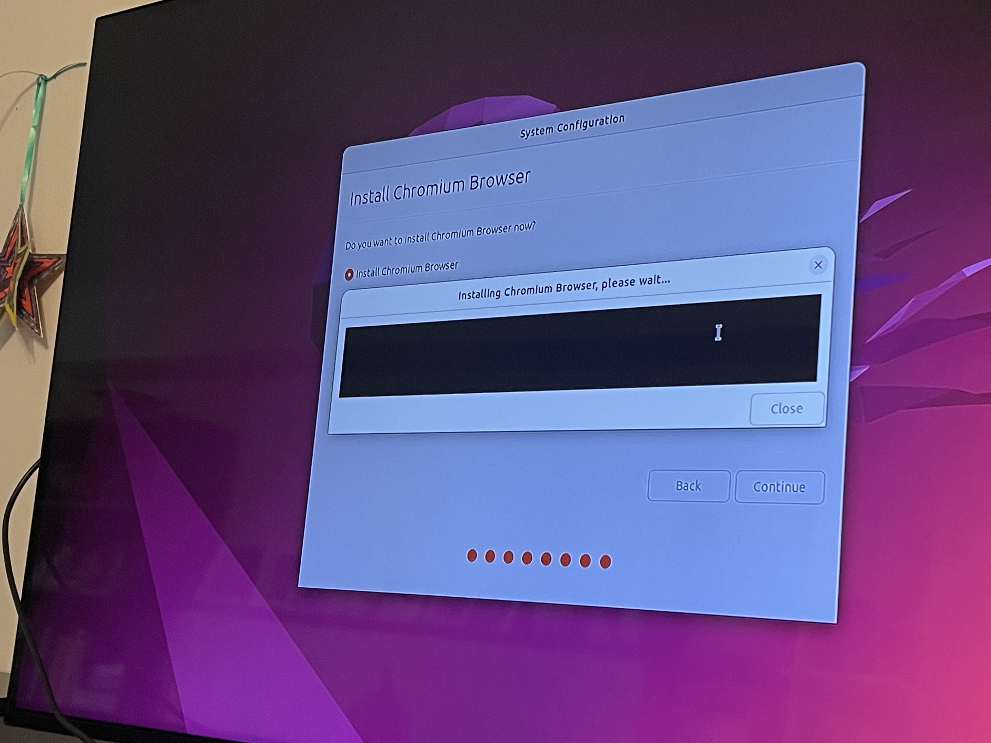
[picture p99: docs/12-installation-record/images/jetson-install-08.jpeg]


**just skip it**

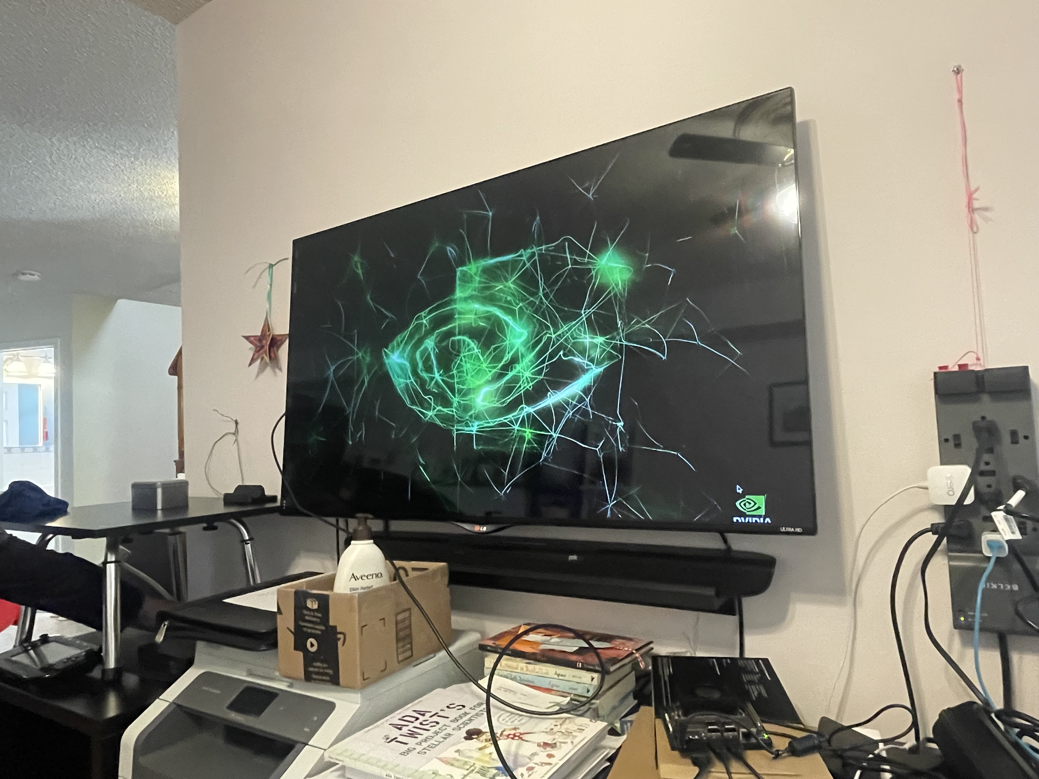
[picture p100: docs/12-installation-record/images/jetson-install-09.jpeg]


jetson user:
`<team-github-account>`
jetson password:
`<...>`

### login in the system and finished the initial setup

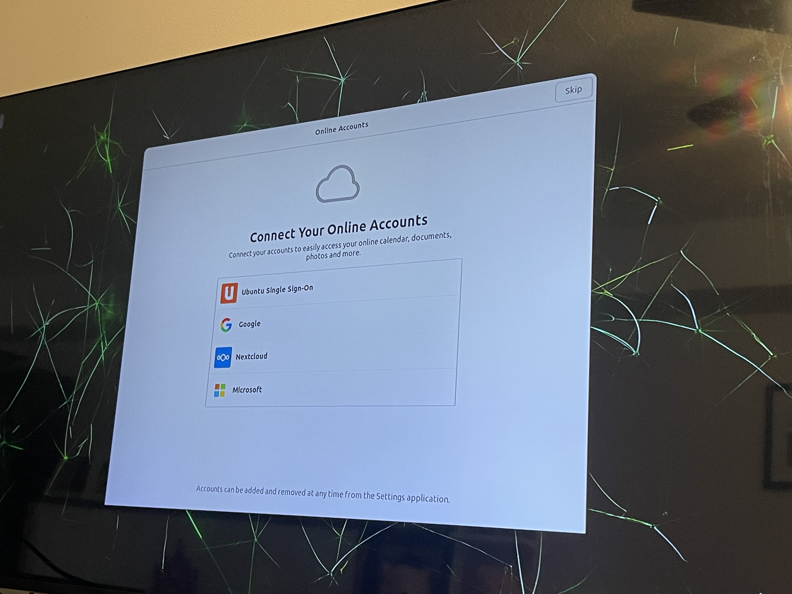
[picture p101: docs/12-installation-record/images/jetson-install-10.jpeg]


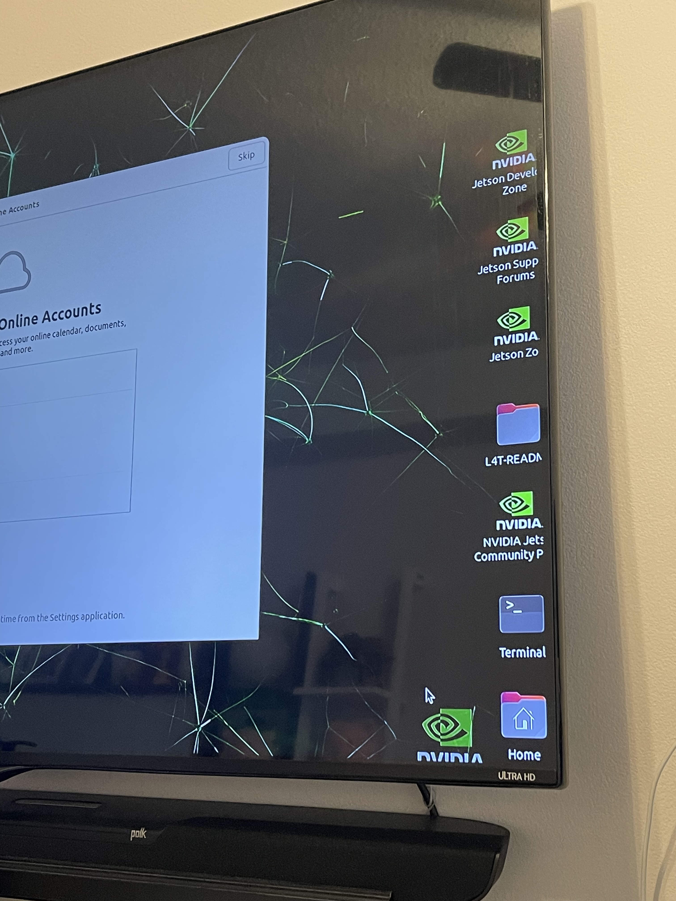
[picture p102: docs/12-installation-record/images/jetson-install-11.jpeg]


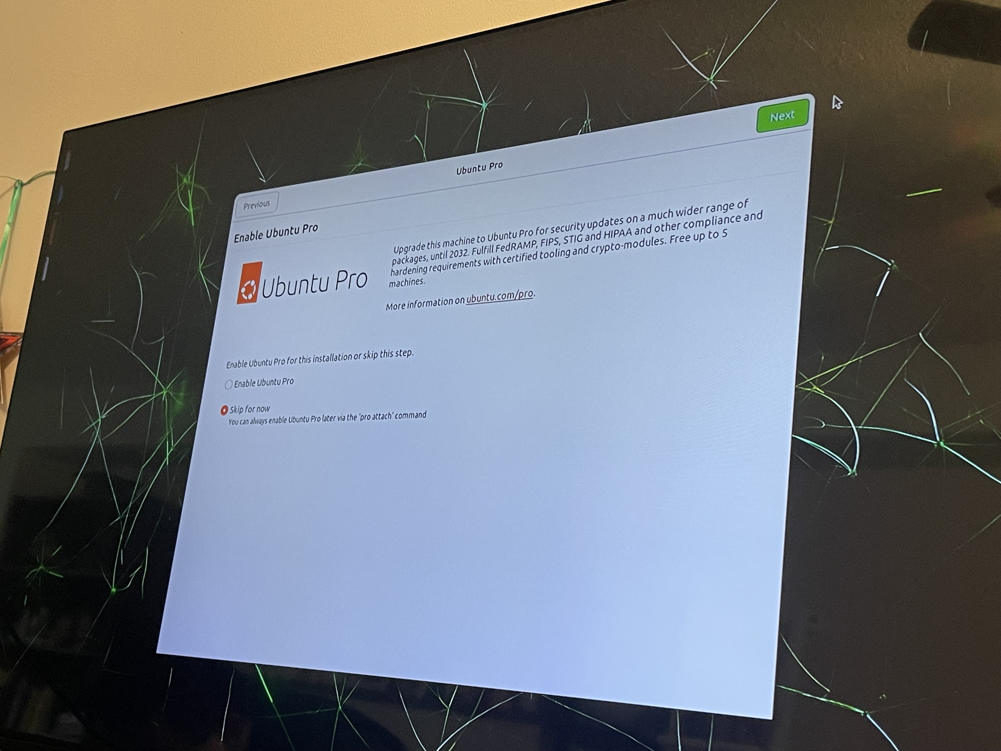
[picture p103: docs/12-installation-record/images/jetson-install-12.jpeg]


### Install chromium after you login
open a terminal

input:
```
sudo apt update
sudo apt install chromium-browser
```

verify chromium installed
snap list chromium

### Command line run chromium
Open a new terminal
```
snap run chromium --no-sandbox --disable-gpu-sandbox --use-gl=egl
```

### Install software updated

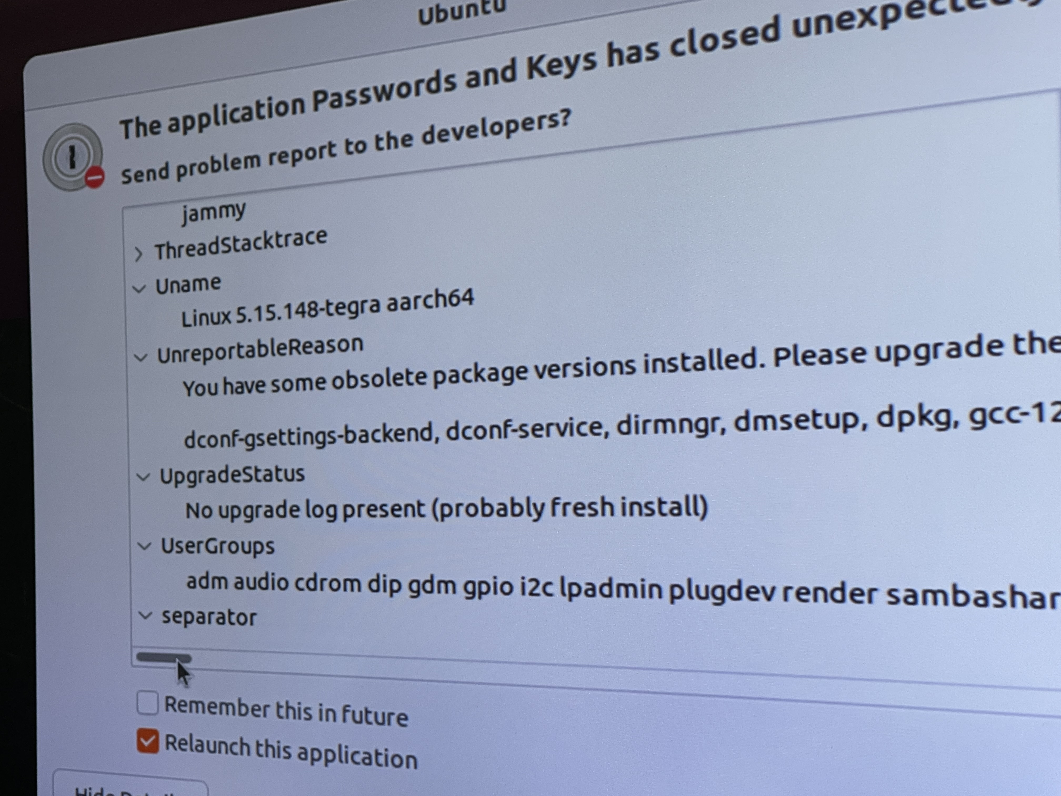
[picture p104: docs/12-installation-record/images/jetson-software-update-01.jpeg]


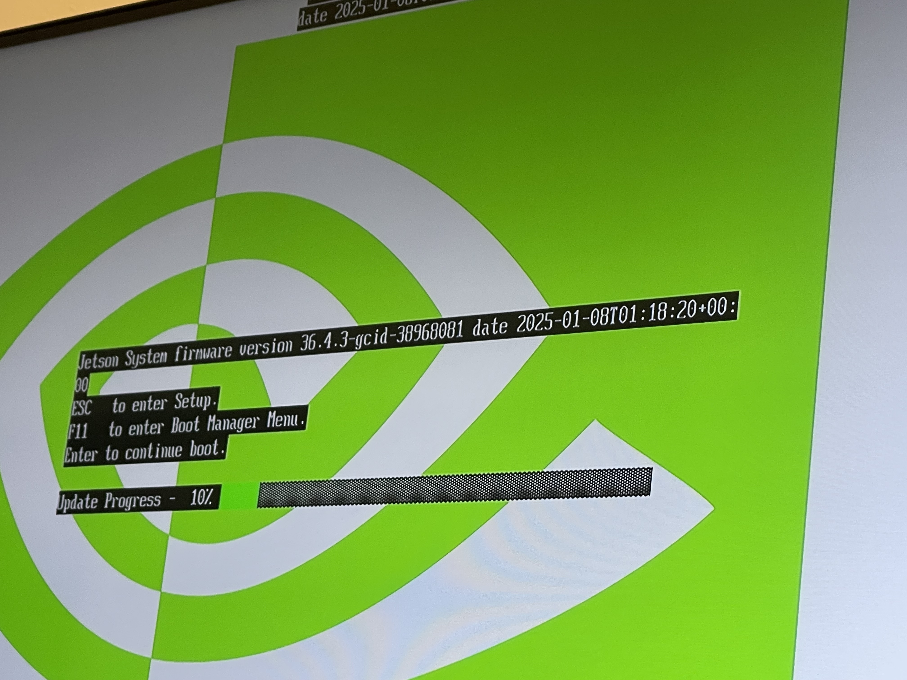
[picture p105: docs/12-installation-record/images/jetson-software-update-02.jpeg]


After install software upated the system need to **reboot**

## Jetson config SSD and move Docker folder to SSD disk
https://www.jetson-ai-lab.com/tips_ssd-docker.html

The SSD is used as a data disk and for Docker storage; it is not used as the system disk.

You may encounter during this process:
```
Failed to restart docker.service: Unit is masked
```
and
```
Failed to restart docker.socket: Unit is masked
```
To fix this, do:
```
sudo systemctl unmask docker
sudo systemctl unmask docker.socket
```

## Jetson config a static network interface address
jetson static ip address setting

### Open GUI network setting
Click the grid icon in the bottom-left corner, then type “network” in the search bar at the top and open Advanced Network.

Edit your Wi-Fi SSID name, go to IPv4 Settings, and change the Method from Automatic (DHCP) to Manual.

### Get jetson current ip address:
open a new terminal, input:

```
ifconfig
```

get address and netmask

input ip route get gateway

### Go back to "Advanced Network" setting and config ip / networkmask / gateway
address add `192.168.2.106` (This is my home's example, you should change to your home's setting）

netmask：`255.255.255.0`

gateway: `192.168.2.1` (This is my home's example, you should change to your home's setting）

### Check your home dns server setting:
```
nmcli dev show wlP1p1s0 | grep DNS
```

### Go back to "Advanced Network" setting and config DNS Server
Multiple dns use comma to separate:
```
192.168.2.1,207.164.234.129
```
(This is my home's example, you should change to your home's setting）

### SSH to Jetson using local hostname
```
ssh <your-jetson-username>@<your-jetson-hostname>.local
ssh <team-user>@<jetson-host>.local
```

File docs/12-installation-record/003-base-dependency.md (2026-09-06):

# Jetson install Base Dependencies

## Install the basic dependency packages required for C++ compilation on the Jetson
**run as user <team-github-account>**
```
sudo apt-get update
sudo apt-get install -y build-essential

sudo apt-get install git wget flex bison gperf python3 python3-pip python3-venv cmake ninja-build ccache libffi-dev libssl-dev dfu-util libusb-1.0-0
```

## Check jetson/ubuntu default python3 version
```
root@ubunturos2:$HOME# python3 -V
Python 3.10.12
```

## Jetson install vscode

```
apt install software-properties-common apt-transport-https wget gpg
wget -qO- https://packages.microsoft.com/keys/microsoft.asc | gpg --dearmor > packages.microsoft.gpg

sudo install -D -o root -g root -m 644 packages.microsoft.gpg /usr/share/keyrings/packages.microsoft.gpg

vi /etc/apt/sources.list.d/vscode.list
deb [arch=arm64 signed-by=/usr/share/keyrings/packages.microsoft.gpg] https://packages.microsoft.com/repos/code stable main
apt update
apt install code

code --version
```

## jetson run vscode(code)
### Open VS Code from the graphical interface
Click the grid icon (the app launcher) in the bottom left corner.
In the search bar at the top, type code.
You will see Visual Studio Code in the results — double-click to open it.

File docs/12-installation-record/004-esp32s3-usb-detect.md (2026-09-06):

# Plugin esp32s3 and detect the correct USB Port

## Check esp32s3 in which port

Now, connect the ESP32 development board to your laptop or jetson and check which serial port the board is using.

Typically, the serial port name appears differently depending on the operating system:

**Linux**: starts with `/dev/tty` (For jetson or your linux laptop)

**macOS**: starts with `/dev/cu.` (For your personal macbook)
```
<team-user>@<jetson-host> test % ls -l /dev/cu*
crw-rw-rw-  1 root  wheel  0x9000001  3 Oct 13:43 /dev/cu.Bluetooth-Incoming-Port
crw-rw-rw-  1 root  wheel  0x9000003 20 Oct 20:33 /dev/cu.usbmodem1101
```

**if you are using macOS you only need to know your port is /dev/cu.usbmodem1101**

## Below is for jetson only

### Check lsusb see if we see ESP32s3 board connected
```
root@<jetson-host>:$HOME/esp/esp-idf# lsusb
Bus 002 Device 002: ID 0bda:0489 Realtek Semiconductor Corp. 4-Port USB 3.0 Hub
Bus 002 Device 001: ID 1d6b:0003 Linux Foundation 3.0 root hub
Bus 001 Device 003: ID 13d3:3549 IMC Networks Bluetooth Radio
Bus 001 Device 005: ID 093a:2521 Pixart Imaging, Inc. Optical Mouse
Bus 001 Device 004: ID 258a:0001 SINO WEALTH USB KEYBOARD
Bus 001 Device 002: ID 0bda:5489 Realtek Semiconductor Corp. 4-Port USB 2.0 Hub
Bus 001 Device 006: ID 303a:1001 **Espressif USB JTAG/serial debug unit**
Bus 001 Device 001: ID 1d6b:0002 Linux Foundation 2.0 root hub
```

### Below is our esp32s3
```
Bus 001 Device 006: ID 303a:1001 Espressif USB JTAG/serial debug unit
```

### use dmesg to confirm the esp32s3 device port name
```
root@<jetson-host>:$HOME/esp/esp-idf# dmesg | grep tty
[    0.000000] Kernel command line: root=/dev/mmcblk0p1 rw rootwait rootfstype=ext4 mminit_loglevel=4 console=ttyTCU0,115200 firmware_class.path=/etc/firmware fbcon=map:0 nospectre_bhb video=efifb:off console=tty0 bl_prof_dataptr=2031616@0x271E10000 bl_prof_ro_ptr=65536@0x271E00000
[    0.000387] printk: console [tty0] enabled
[    0.069021] 31d0000.serial: ttyAMA0 at MMIO 0x31d0000 (irq = 117, base_baud = 0) is a SBSA
[    0.201220] printk: console [ttyTCU0] enabled
[    3.109580] printk: console [tty0]: printing thread started
[    3.109638] printk: console [ttyTCU0]: printing thread started
[    3.165632] 3100000.serial: ttyTHS1 at MMIO 0x3100000 (irq = 112, base_baud = 0) is a TEGRA_UART
[    3.166189] 3140000.serial: ttyTHS2 at MMIO 0x3140000 (irq = 113, base_baud = 0) is a TEGRA_UART
[    8.703407] systemd[1]: Created slice Slice /system/serial-getty.
[ 2770.910658] cdc_acm 1-1:1.0: **ttyACM0: USB ACM device**
root@<jetson-host>:$HOME/esp/esp-idf#
```

### Below is esp32s3 device port name
```
cdc_acm 1-1:1.0: ttyACM0: USB ACM device
```

### If installed esp-idf then we need to reload the rules, give the device permission to plugdev group
**some examples**
```
sudo cp -n $HOME/.espressif/tools/openocd-esp32/v0.12.0-esp32-**20250707**/openocd-esp32/share/openocd/contrib/60-openocd.rules /etc/udev/rules.d
sudo cp -n $HOME/.espressif/tools/openocd-esp32/v0.12.0-esp32-**20241016**/openocd-esp32/share/openocd/contrib/60-openocd.rules /etc/udev/rules.d

<team-user>@<jetson-host>:~$ ls -l /etc/udev/rules.d
total 128
-rw-r--r-- 1 root root   204 Jan  7  2025 10-nv-jetson-dm.rules
-rw-r--r-- 1 root root 23513 Oct 25 11:20 70-snap.chromium.rules
-rw-r--r-- 1 root root   758 Oct 25 10:59 70-snap.cups.rules
-rw-r--r-- 1 root root 63357 Oct 25 10:59 70-snap.snapd.rules
-rw-r--r-- 1 root root   175 Jan  7  2025 91-xorg-conf-tegra.rules
-rw-r--r-- 1 root root   777 Jan  7  2025 99-nv-l4t-usb-device-mode.rules
-rw-r--r-- 1 root root  1448 Jan  7  2025 99-nv-l4t-usb-host-config.rules
-rw-r--r-- 1 root root   907 Jan  7  2025 99-nv-ufs-mount.rules
-rw-r--r-- 1 root root  1114 Jan  7  2025 99-nv-wifibt.rules
-rw-r--r-- 1 root root  5092 Jan  7  2025 99-tegra-devices.rules
-rw-r--r-- 1 root root   130 Jan  7  2025 99-tegra-mmc-ra.rules
<team-user>@<jetson-host>:~$
```

### Check esp32s3 device user/group permission before change
```
<team-user>@<jetson-host>:~$ ls -l /dev/ttyACM*
crw-rw---- 1 root **dialout** 166, 0 Oct 25 15:08 /dev/ttyACM0

lsusb
Bus 002 Device 002: ID 0bda:0489 Realtek Semiconductor Corp. 4-Port USB 3.0 Hub
Bus 002 Device 001: ID 1d6b:0003 Linux Foundation 3.0 root hub
Bus 001 Device 003: ID 13d3:3549 IMC Networks Bluetooth Radio
Bus 001 Device 005: ID 093a:2521 Pixart Imaging, Inc. Optical Mouse
Bus 001 Device 004: ID 258a:0001 SINO WEALTH USB KEYBOARD
Bus 001 Device 002: ID 0bda:5489 Realtek Semiconductor Corp. 4-Port USB 2.0 Hub
Bus 001 Device 009: ID 303a:1001 Espressif USB JTAG/serial debug unit
Bus 001 Device 001: ID 1d6b:0002 Linux Foundation 2.0 root hub
```

### Copy the rules and reload to fix the device user/group permission
```
sudo cp -n $HOME/.espressif/tools/openocd-esp32/v0.12.0-esp32-20250707/openocd-esp32/share/openocd/contrib/60-openocd.rules /etc/udev/rules.d/
sudo udevadm control --reload-rules
sudo udevadm trigger
```

### Check esp32s3 device user/group permission againa after change
```
<team-user>@<jetson-host>:~$ sudo udevadm trigger
<team-user>@<jetson-host>:~$ ls -l /dev/ttyACM*
crw-rw----+ 1 root **plugdev** 166, 0 Oct 25 16:40 /dev/ttyACM0
<team-user>@<jetson-host>:~$ lsusb
Bus 002 Device 002: ID 0bda:0489 Realtek Semiconductor Corp. 4-Port USB 3.0 Hub
Bus 002 Device 001: ID 1d6b:0003 Linux Foundation 3.0 root hub
Bus 001 Device 003: ID 13d3:3549 IMC Networks Bluetooth Radio
Bus 001 Device 005: ID 093a:2521 Pixart Imaging, Inc. Optical Mouse
Bus 001 Device 004: ID 258a:0001 SINO WEALTH USB KEYBOARD
Bus 001 Device 002: ID 0bda:5489 Realtek Semiconductor Corp. 4-Port USB 2.0 Hub
Bus 001 Device 009: ID 303a:1001 Espressif USB JTAG/serial debug unit
Bus 001 Device 001: ID 1d6b:0002 Linux Foundation 2.0 root hub
```

### To prevent error, at linux, add user to dialout group

The currently logged-in user must have permission to read from and write to the serial port over USB.

In most Linux distributions, you can grant this permission by adding the user to the dialout group with the following command:

```
sudo usermod -a -G dialout <team-github-account>
```

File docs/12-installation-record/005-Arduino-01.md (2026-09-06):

# Arduino IDE  / ESP32

**Arduino IDE we will using version 2.3.6**

## Architecture diagram

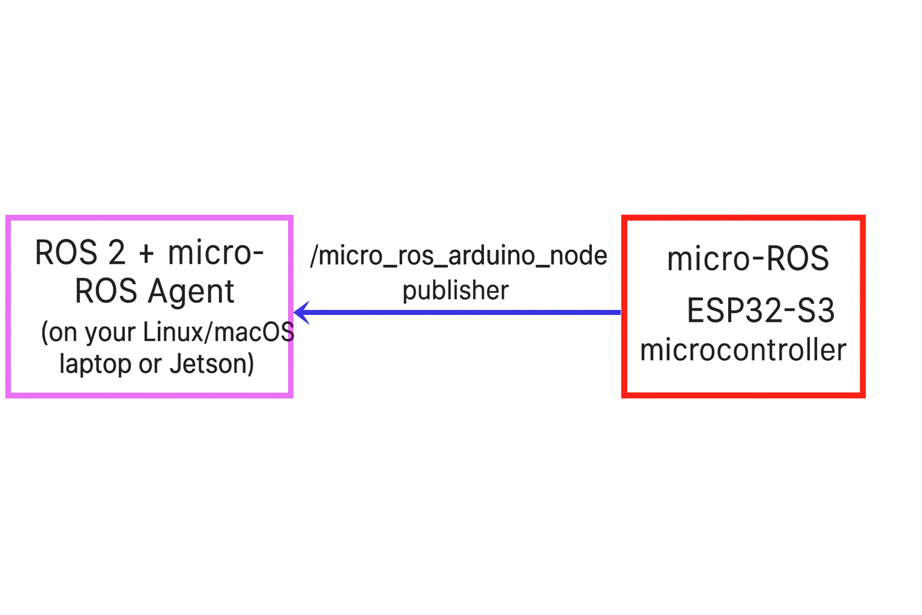
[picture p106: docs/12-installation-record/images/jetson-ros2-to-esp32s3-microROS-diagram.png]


## Table of Content
1. How to install Arduino IDE in Linux(Jetson) / Macbook/ Windows from scratch.
2. How to install an ESP32 board in Arduino IDE.
3. How to install micro-ROS for Arduino library.
4. How to install  Arduino other library.
5. How to flash our project arduino code.

[005-Arduino-Jetson](./005-Arduino-Jetson.md)

[005-Arduino-MacBook](./005-Arduino-MacBook.md)

[005-Arduino-Windows](./005-Arduino-Windows.md)

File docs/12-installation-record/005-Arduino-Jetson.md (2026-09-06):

## Linux Ubuntu 22.04 install Arduino IDE and setup ROS2 + microROS

See guide from below youtube video

[Properly Create ROS2-Arduino IDE (ESP32) Interface - Solution Based on the microROS2 Library](https://www.youtube.com/watch?v=0R8VUPEkYhg&list=PL8lID45FIDTS-eRyAXY6iCQcMB-Bxi-8D)

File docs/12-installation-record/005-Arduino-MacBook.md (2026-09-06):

## Macbook - Install Arduino IDE from scratch
```
brew install --cask arduino-ide
```

### `brew info arduino-ide`
```
==> arduino-ide: 2.3.6
https://www.arduino.cc/en/software
Installed
/opt/homebrew/Caskroom/arduino-ide/2.3.6 (525MB)
From: https://github.com/Homebrew/homebrew-cask/blob/HEAD/Casks/a/arduino-ide.rb
==> Name
Arduino IDE
==> Description
Electronics prototyping platform
==> Artifacts
Arduino IDE.app (App)
==> Analytics
install: 626 (30 days), 1,867 (90 days), 7,096 (365 days)
```

**Go to your Launchpad and double click "Arduino IDE".**

`"Arduino IDE" is an app downloaded from the internet. Are you sure you want to open it?`

**Choose "Open"**

### Install ESP32 Library in Arduino IDE
https://docs.espressif.com/projects/arduino-esp32/en/latest/installing.html

Copy below link

https://espressif.github.io/arduino-esp32/package_esp32_index.json

Go to Arduino IDE, open setting
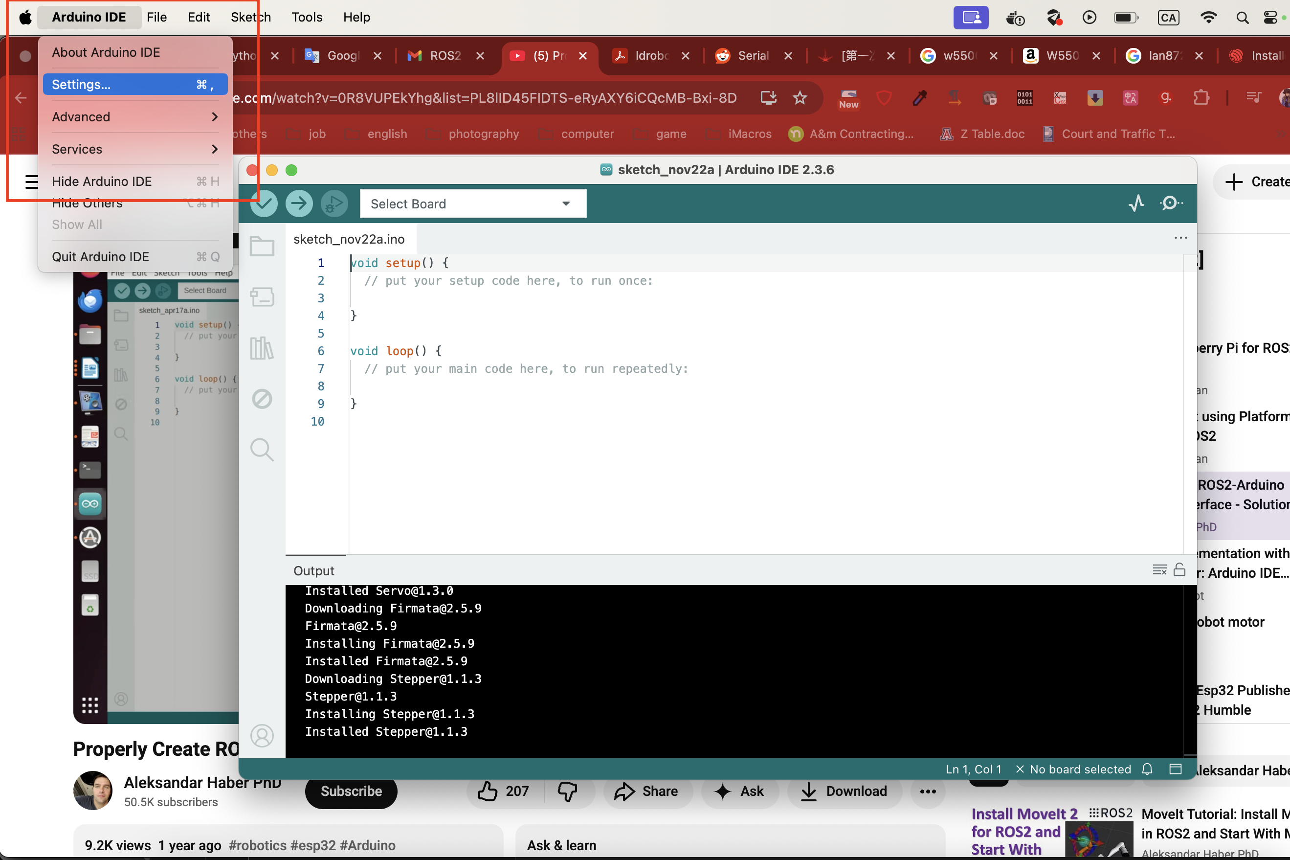
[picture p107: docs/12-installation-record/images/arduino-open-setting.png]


Paste the link at "Additional boards manager URLs" and click "ok"
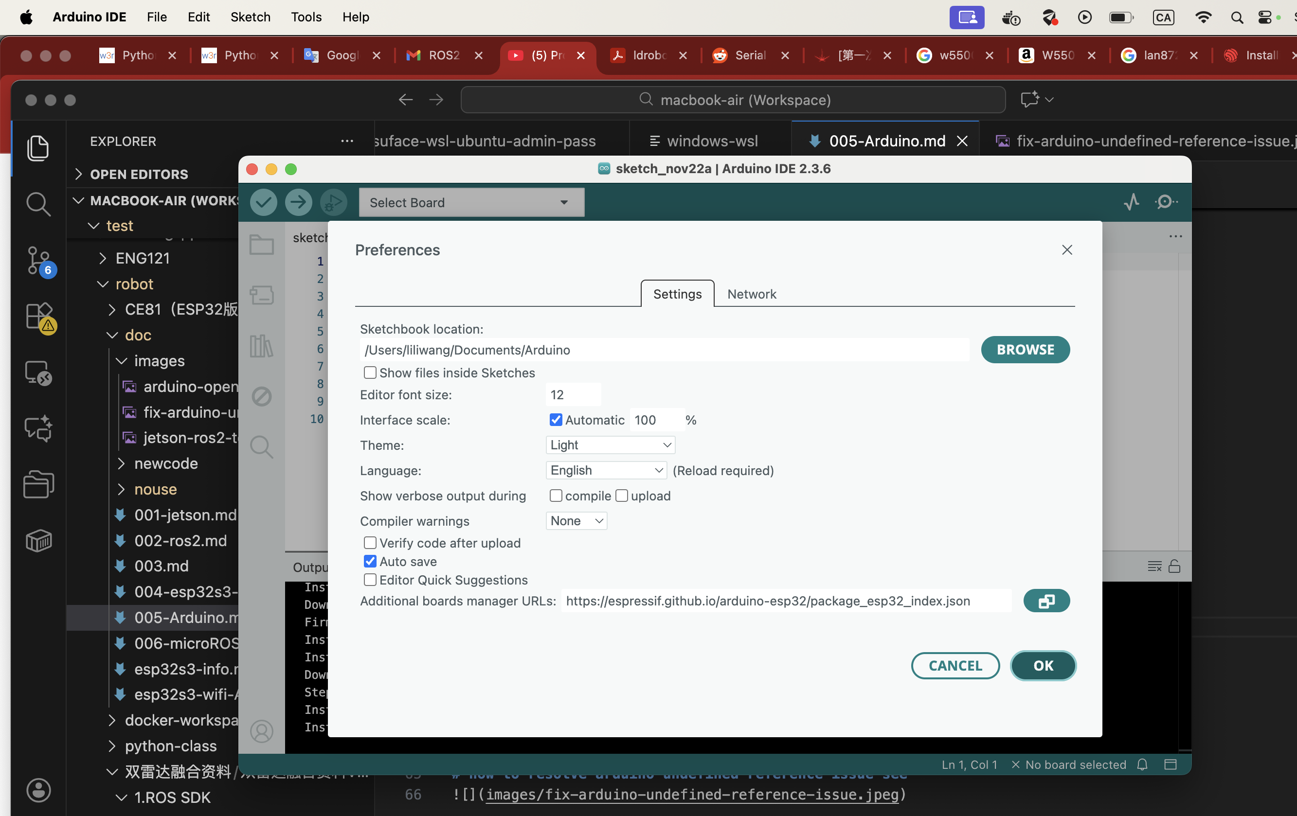
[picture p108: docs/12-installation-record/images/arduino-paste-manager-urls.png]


Installing ESP32 Board Package in Arduino IDE
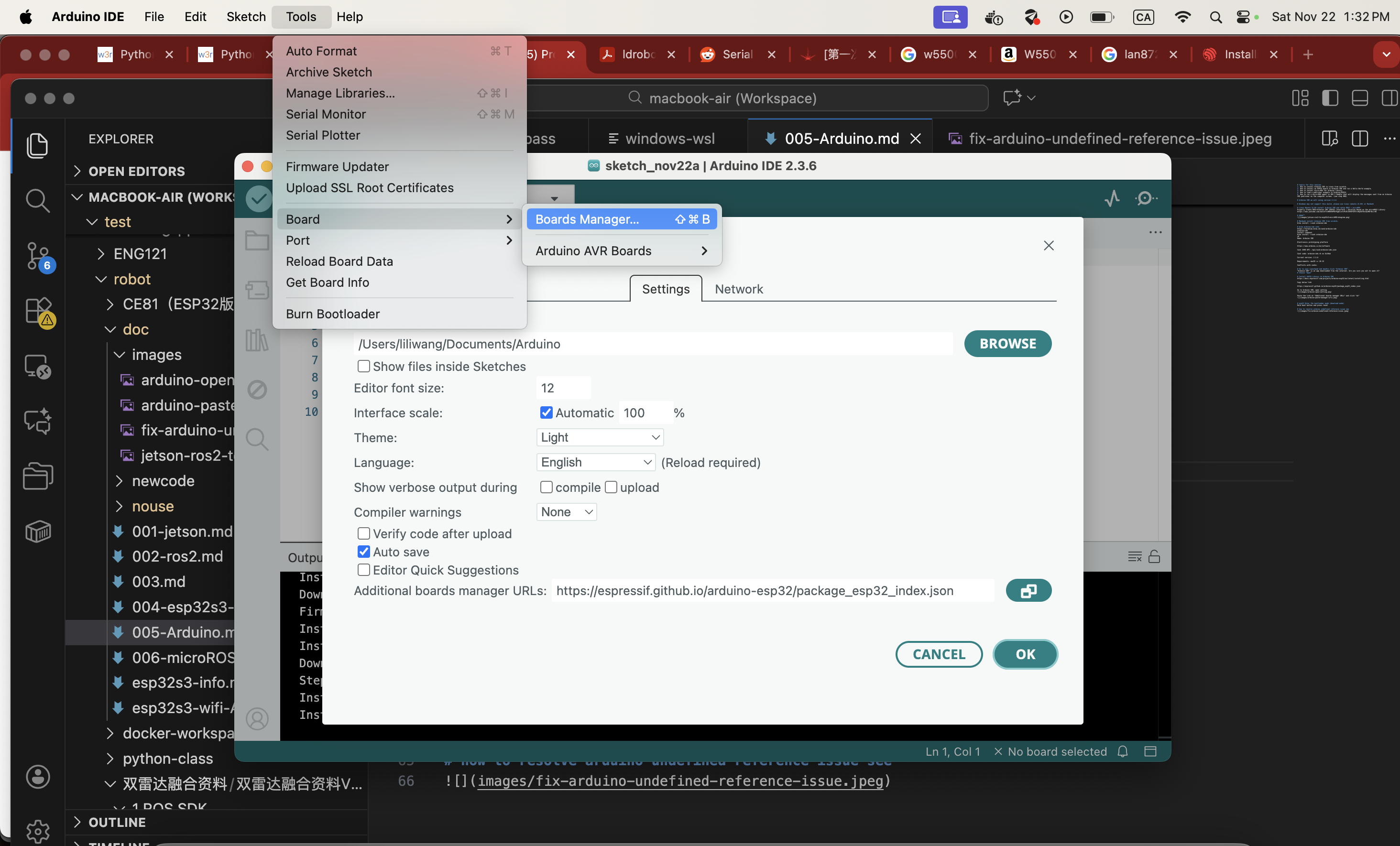
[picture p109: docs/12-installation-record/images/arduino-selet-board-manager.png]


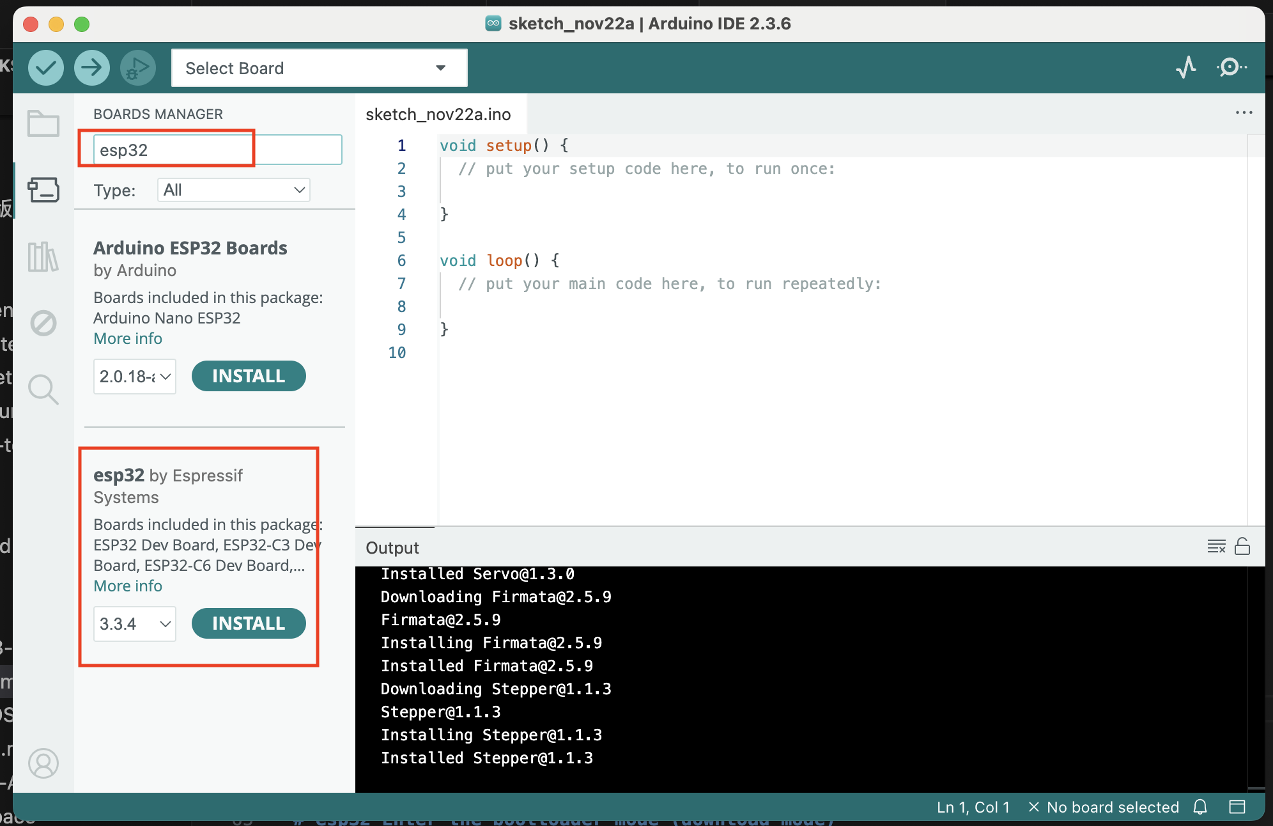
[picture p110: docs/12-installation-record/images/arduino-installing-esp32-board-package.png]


ESP32 Board Package we are using "esp32 by Espressif Systems" (version 3.3.4), click "INSTALL"

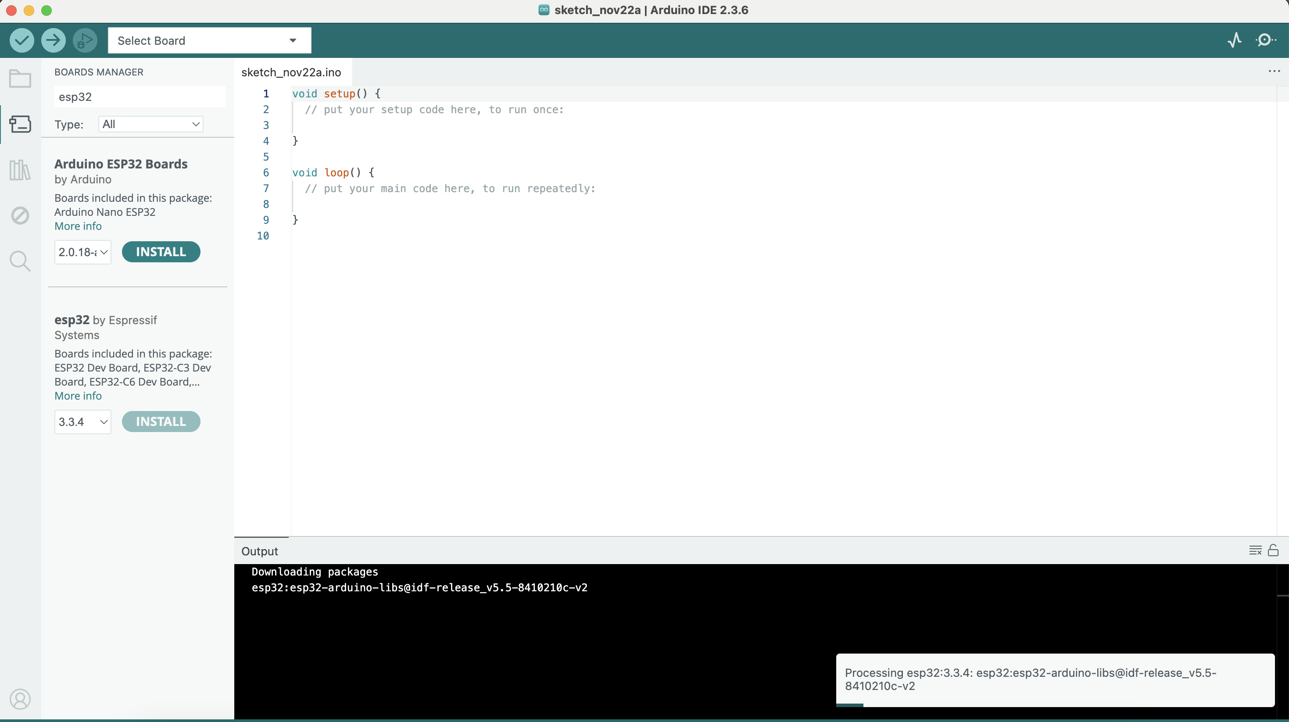
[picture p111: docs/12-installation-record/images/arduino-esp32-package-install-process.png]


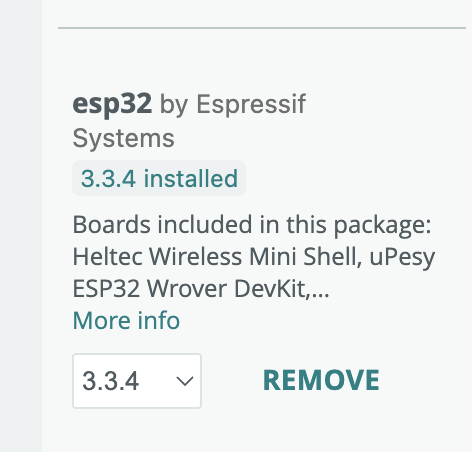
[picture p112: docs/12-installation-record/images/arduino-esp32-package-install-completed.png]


### Install micro-ROS for Arduino library.
Download micro_ros for Arduino ESP32 Core (with minor patch) (version 2.0.8-humble)

Go to
https://github.com/micro-ROS/micro_ros_arduino

Select branch "humble"
https://github.com/micro-ROS/micro_ros_arduino/tree/humble

Go to
https://github.com/micro-ROS/micro_ros_arduino/releases
Find v2.0.8-humble

Expand "Assets"

Download "Source code (zip)"

Link:
https://github.com/micro-ROS/micro_ros_arduino/archive/refs/tags/v2.0.8-humble.zip

Save the zip file to $HOME/Documents/Arduino

```
<team-user>@<jetson-host> Arduino % pwd
$HOME/Documents/Arduino
<team-user>@<jetson-host> Arduino % ls
micro_ros_arduino-2.0.8-humble.zip
<team-user>@<jetson-host> Arduino % ls -l
total 32912
-rw-r--r--@ 1 <local-user>  staff  16849977 22 Nov 14:40 micro_ros_arduino-2.0.8-humble.zip
<team-user>@<jetson-host> Arduino %
```

Install micro_ros_arduino-2.0.8-humble.zip at Arduino
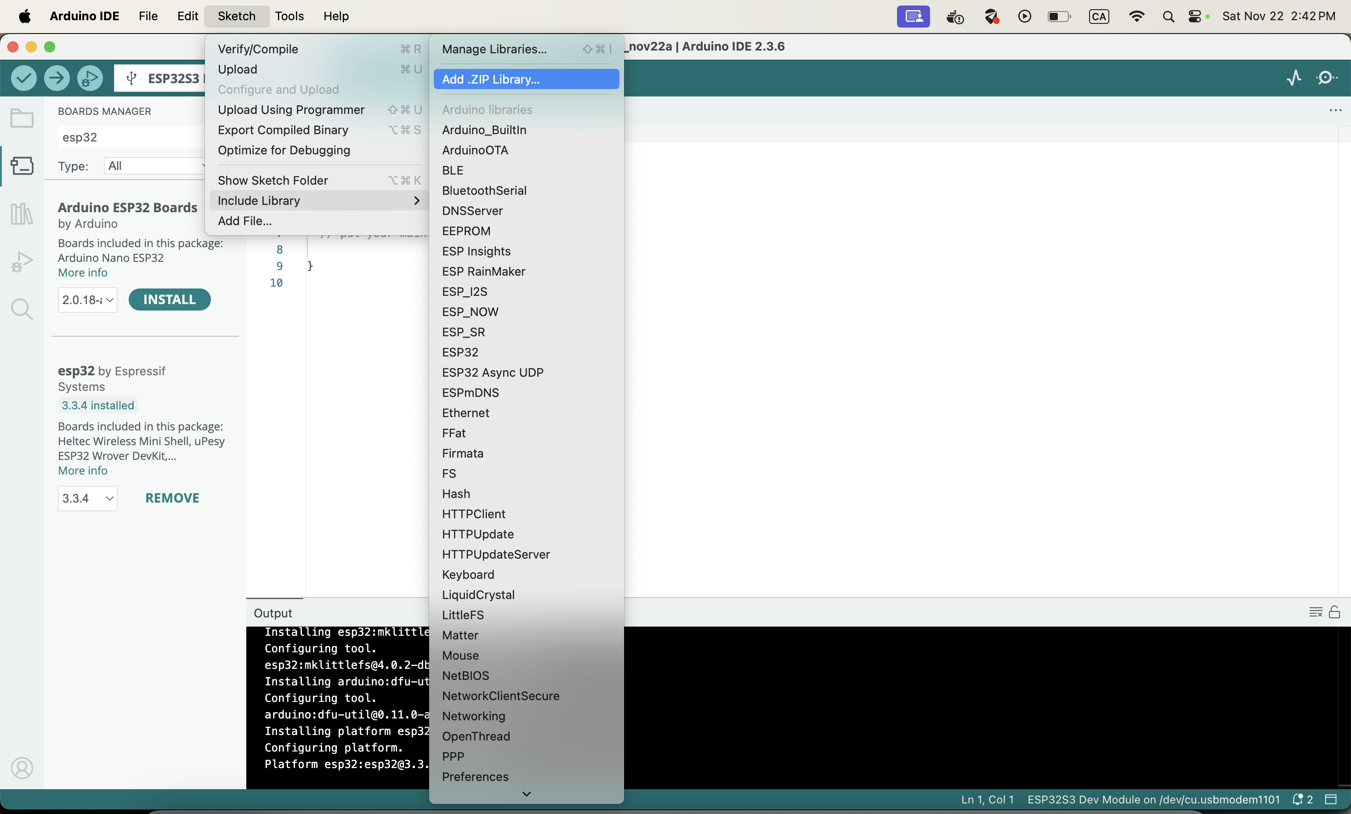
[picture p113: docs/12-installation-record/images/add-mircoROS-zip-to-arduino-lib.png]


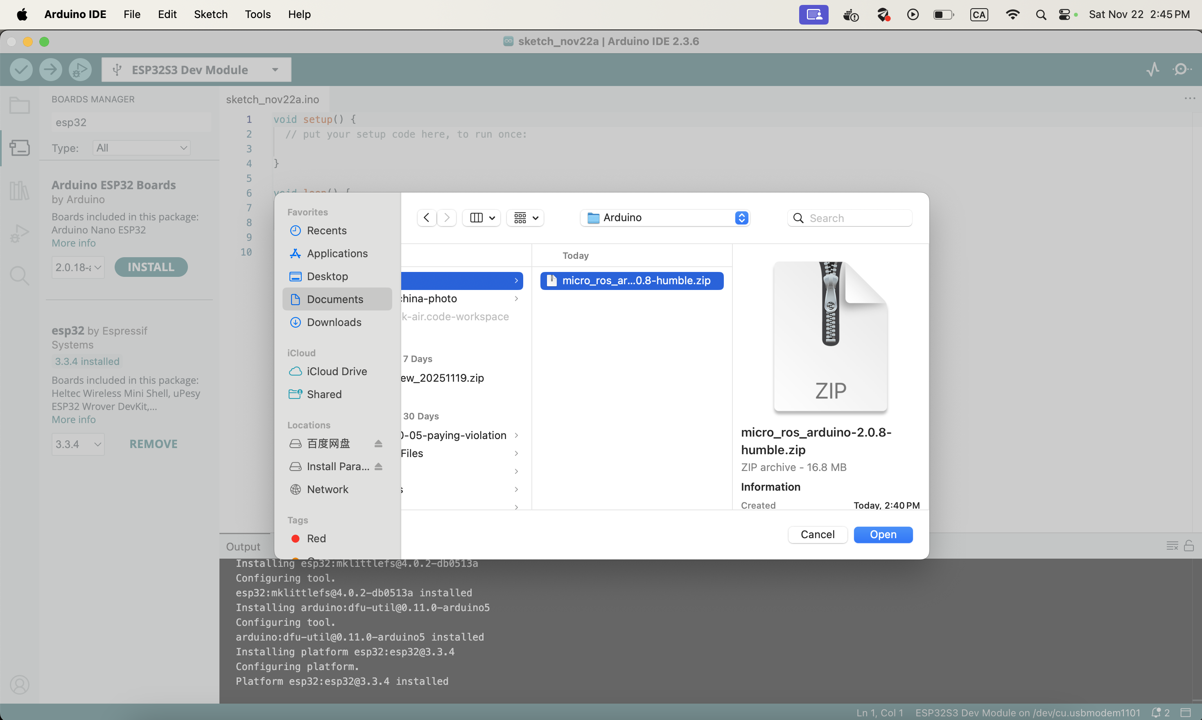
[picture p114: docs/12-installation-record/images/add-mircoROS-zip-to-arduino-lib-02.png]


Click Open, then at Arduino IDE terminal see message "Library Installed"
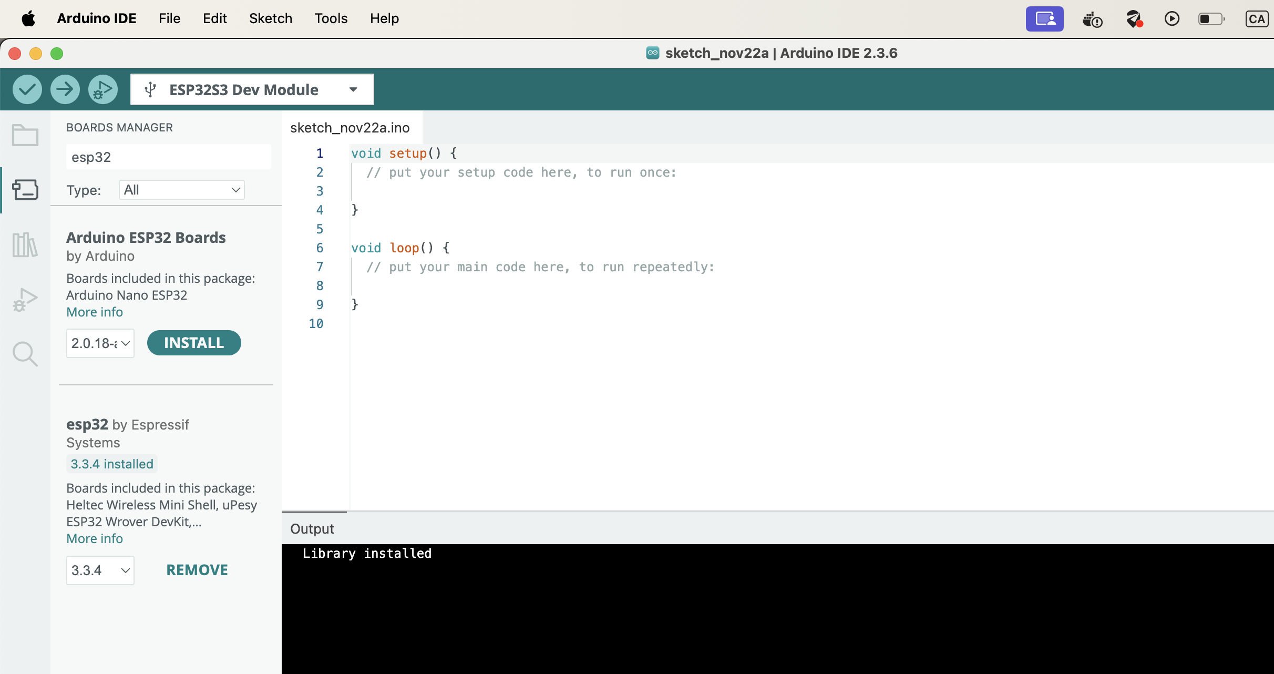
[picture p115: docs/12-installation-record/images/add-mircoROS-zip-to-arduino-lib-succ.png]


Go back to $HOME/Documents/Arduino, you will see libraries/micro_ros_arduino folder
This is a precompiled library

```
<team-user>@<jetson-host> Arduino % ls -l
total 32912
drwxr-xr-x  3 <local-user>  staff        96 22 Nov 14:46 libraries
-rw-r--r--@ 1 <local-user>  staff  16849977 22 Nov 14:40 micro_ros_arduino-2.0.8-humble.zip
<team-user>@<jetson-host> Arduino % ls -l libraries
total 0
drwxr-xr-x  16 <local-user>  staff  512 22 Nov 14:46 micro_ros_arduino
<team-user>@<jetson-host> Arduino %
```

### Install U8g2 library for OLED display
U8g2 library for Arduino IDE (version 2.35.30)

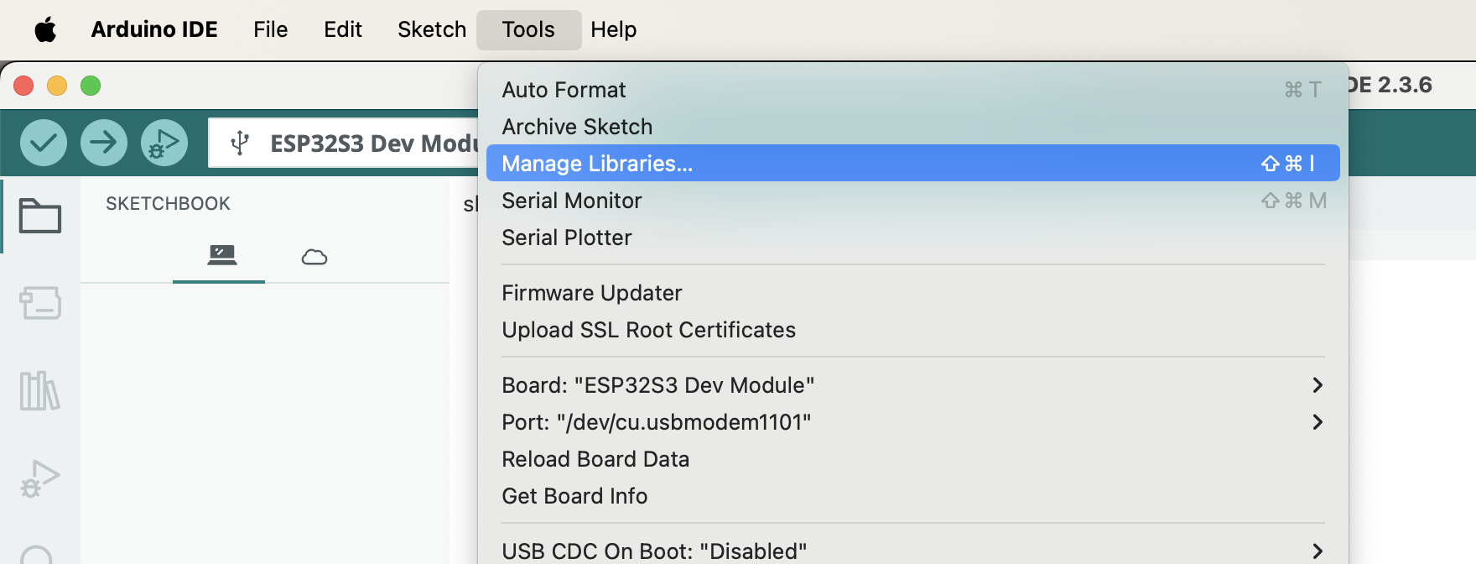
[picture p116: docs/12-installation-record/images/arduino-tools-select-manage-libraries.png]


search U8g2
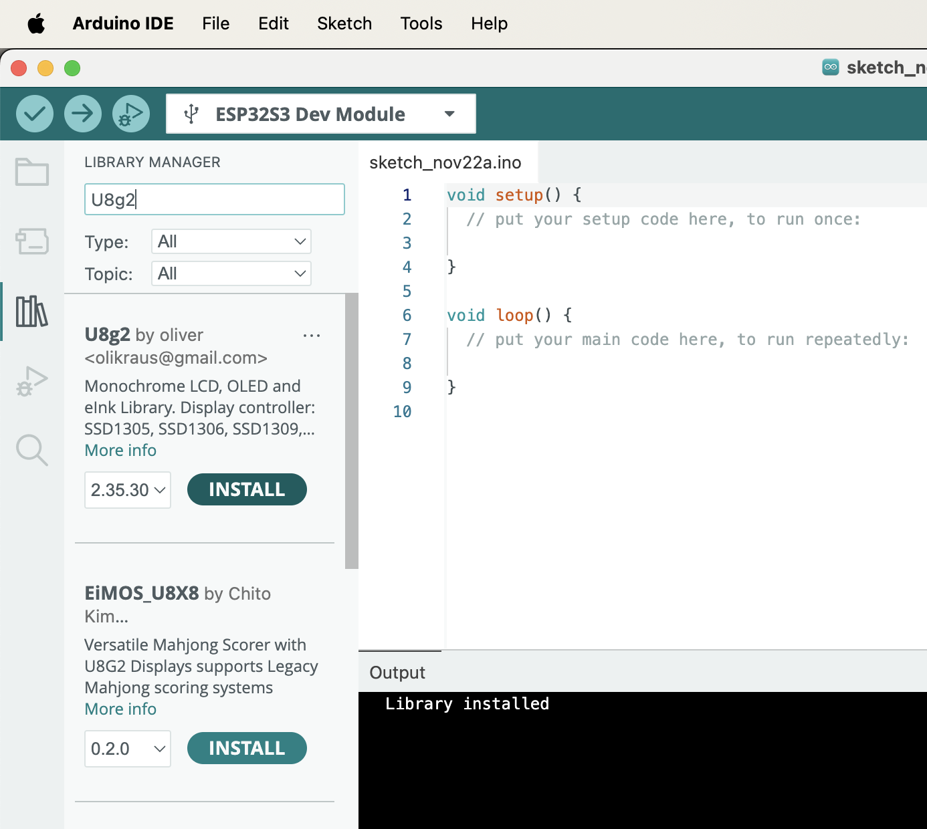
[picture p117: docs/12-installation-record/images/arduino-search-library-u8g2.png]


Click "INSTALL", wait to completed
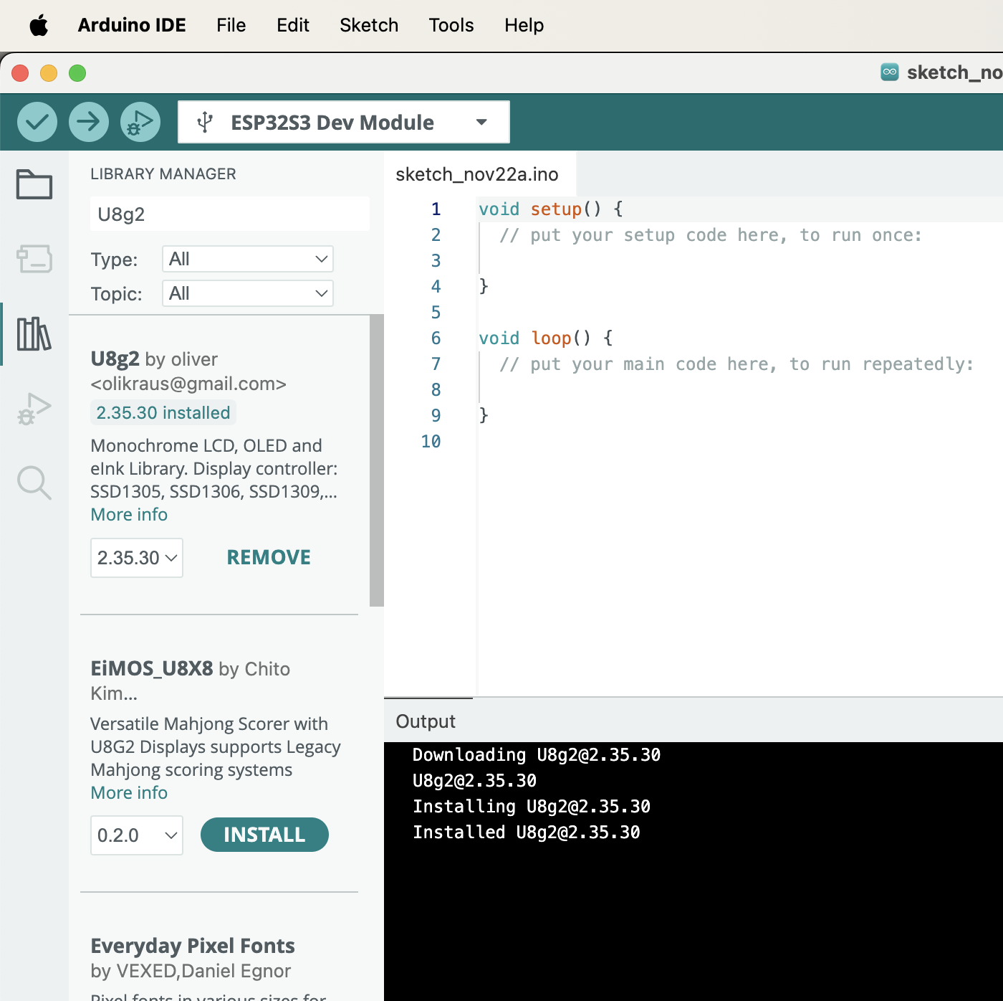
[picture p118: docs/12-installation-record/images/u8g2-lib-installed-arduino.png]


### Install arduino-audio-driver library

[arduino-audio-driver Github Repo](https://github.com/pschatzmann/arduino-audio-driver)

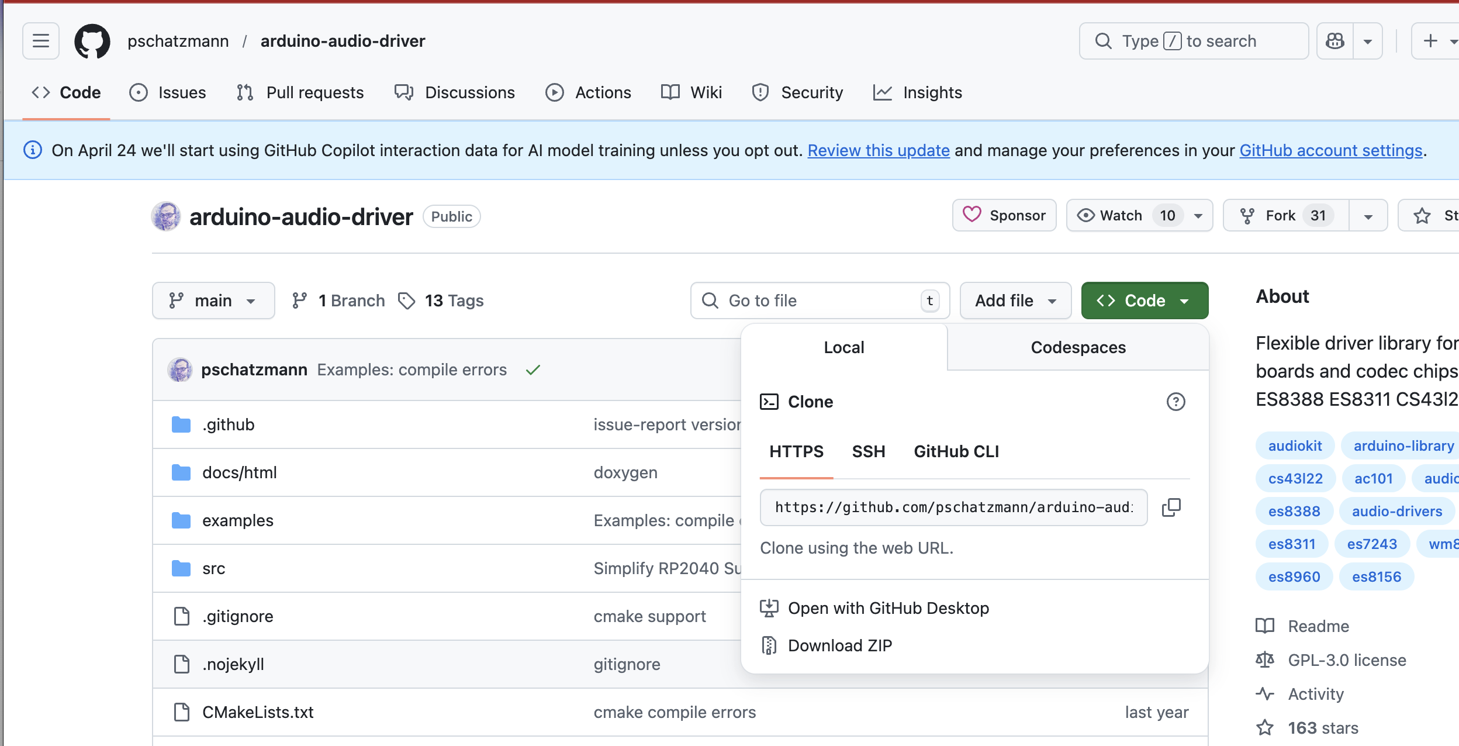
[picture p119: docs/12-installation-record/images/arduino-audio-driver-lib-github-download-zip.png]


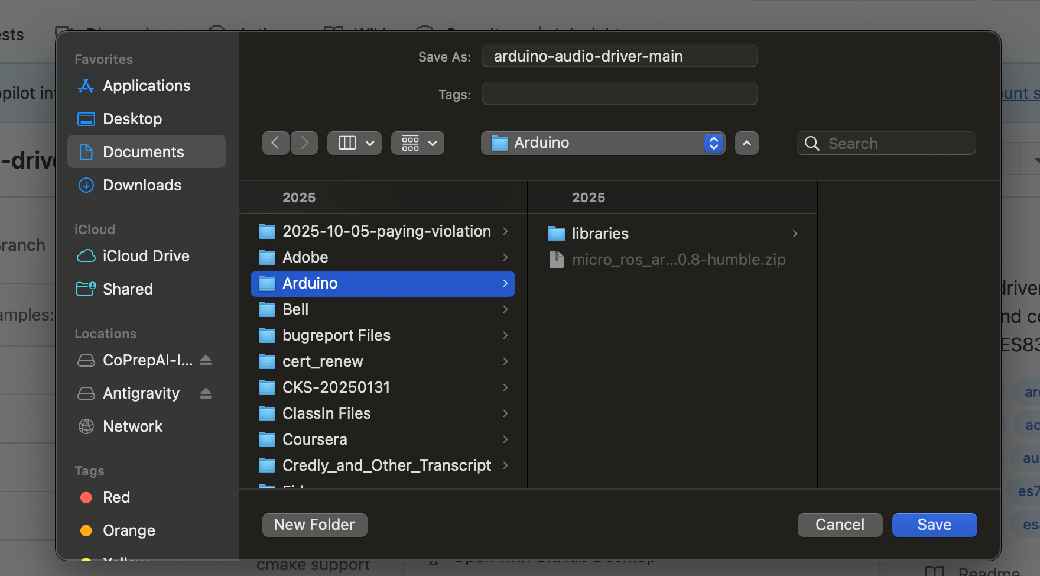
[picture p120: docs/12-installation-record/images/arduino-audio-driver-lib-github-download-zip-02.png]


Rename the github download zip file

```bash
mv arduino-audio-driver-main.zip arduino-audio-driver.zip
```







### C++ code for Arduino IDE/ESP32s3/MicroROS

Our code is at the folder:

`./newcode/esp32-code`

You need to update line 269:

`set_microros_wifi_transports("<WIFI_SSID>", "<WIFI_PASSWORD>", "<AGENT_IP>", 8888)`

<WIFI_SSID> is `<WIFI SSID>`

<WIFI_PASSWORD> is  `<WIFI Password>`

192.168.1.79 is `<Micro ROS Agent IP>`

8888 is `<Micro ROS Agent Port>`

### How to load our esp32 code in Arduino IDE



Code can be at any folder, below is my code path

Remember Arduino IDE can only open "File" not "Directory"

So your **filename must same as Directory name**,  then it will open the whole folder

`$HOME/Documents/test/robot/doc/newcode/esp32-code/esp32-code.ino`



Click "Open", it would open a new "Arduino IDE" window and include the whole folder code



### Arduino IDE prepare for build / flash code to ESP32s3
**Every time before building and flashing the code, you must select the Board and the Port.**

Select ESP32 Board at Arduino IDE




Make sure your esp32s3 is using usb to connect to your macbook

```
<team-user>@<jetson-host> newcode % ls -l /dev/cu*
crw-rw-rw-  1 root  wheel  0x9000001  3 Oct 13:43 /dev/cu.Bluetooth-Incoming-Port
crw-rw-rw-  1 root  wheel  0x9000003 22 Nov 14:24 /dev/cu.usbmodem1101
```

`/dev/cu.usbmodem1101` is ESP32s3 Port

Then select port at Arduino IDE


**Set partition scheme**
Our code is too large for the default partition scheme, so we will have to change the partition scheme.
Go to the menu, select **Tools** -> **Partition Scheme** -> *Minimal SPIFFS (1.9MB APP with OTA/128KB SPIFFS)*.
As an alternative, you can also choose *Huge APP (3MB No OTA/1MB SPIFFS)*.

### Verify Code



compiling


Error:



```
Library micro_ros_arduino has been declared precompiled:
**Precompiled library in "$HOME/Documents/Arduino/libraries/micro_ros_arduino/src/esp32s3" not found**
$HOME/Library/Arduino15/packages/esp32/tools/esp-x32/2507/bin/../lib/gcc/xtensa-esp-elf/14.2.0/../../../../xtensa-esp-elf/bin/ld: $HOME/Library/Caches/arduino/sketches/CF768F34FC47A0606F882E35BAFB02FE/sketch/esp32-code.ino.cpp.o:(.literal._Z12publish_textPKcb+0x1c): undefined reference to `rcl_publish'
$HOME/Library/Arduino15/packages/esp32/tools/esp-x32/2507/bin/../lib/gcc/xtensa-esp-elf/14.2.0/../../../../xtensa-esp-elf/bin/ld: $HOME/Library/Caches/arduino/sketches/CF768F34FC47A0606F882E35BAFB02FE/sketch/esp32-code.ino.cpp.o:(.literal._Z4loopv+0xc): **undefined reference** to `rclc_executor_spin_some'
$HOME/Library/Arduino15/packages/esp32/tools/esp-x32/2507/bin/../lib/gcc/xtensa-esp-elf/14.2.0/../../../../xtensa-esp-elf/bin/ld: $HOME/Library/Caches/arduino/sketches/CF768F34FC47A0606F882E35BAFB02FE/sketch/esp32-code.ino.cpp.o:(.literal._Z5setupv+0x9c): undefined reference to `rmw_uros_set_custom_transport'
$HOME/Library/Arduino15/packages/esp32/tools/esp-x32/2507/bin/../lib/gcc/xtensa-esp-elf/14.2.0/../../../../xtensa-esp-elf/bin/ld: $HOME/Library/Caches/arduino/sketches/CF768F34FC47A0606F882E35BAFB02FE/sketch/esp32-code.ino.cpp.o:(.literal._Z5setupv+0xa0): undefined reference to `rcutils_get_default_allocator'
$HOME/Library/Arduino15/packages/esp32/tools/esp-x32/2507/bin/../lib/gcc/xtensa-esp-elf/14.2.0/../../../../xtensa-esp-elf/bin/ld: $HOME/Library/Caches/arduino/sketches/CF768F34FC47A0606F882E35BAFB02FE/sketch/esp32-code.ino.cpp.o:(.literal._Z5setupv+0xa4): undefined reference to `rclc_support_init'
$HOME/Library/Arduino15/packages/esp32/tools/esp-x32/2507/bin/../lib/gcc/xtensa-esp-elf/14.2.0/../../../../xtensa-esp-elf/bin/ld: $HOME/Library/Caches/arduino/sketches/CF768F34FC47A0606F882E35BAFB02FE/sketch/esp32-code.ino.cpp.o:(.literal._Z5setupv+0xac): undefined reference to `rclc_node_init_default'
$HOME/Library/Arduino15/packages/esp32/tools/esp-x32/2507/bin/../lib/gcc/xtensa-esp-elf/14.2.0/../../../../xtensa-esp-elf/bin/ld: $HOME/Library/Caches/arduino/sketches/CF768F34FC47A0606F882E35BAFB02FE/sketch/esp32-code.ino.cpp.o:(.literal._Z5setupv+0xb0): undefined reference to `rosidl_typesupport_c__get_message_type_support_handle__std_msgs__msg__String'
$HOME/Library/Arduino15/packages/esp32/tools/esp-x32/2507/bin/../lib/gcc/xtensa-esp-elf/14.2.0/../../../../xtensa-esp-elf/bin/ld: $HOME/Library/Caches/arduino/sketches/CF768F34FC47A0606F882E35BAFB02FE/sketch/esp32-code.ino.cpp.o:(.literal._Z5setupv+0xb4): undefined reference to `rclc_publisher_init_default'
$HOME/Library/Arduino15/packages/esp32/tools/esp-x32/2507/bin/../lib/gcc/xtensa-esp-elf/14.2.0/../../../../xtensa-esp-elf/bin/ld: $HOME/Library/Caches/arduino/sketches/CF768F34FC47A0606F882E35BAFB02FE/sketch/esp32-code.ino.cpp.o:(.literal._Z5setupv+0xb8): undefined reference to `std_msgs__msg__String__init'
$HOME/Library/Arduino15/packages/esp32/tools/esp-x32/2507/bin/../lib/gcc/xtensa-esp-elf/14.2.0/../../../../xtensa-esp-elf/bin/ld: $HOME/Library/Caches/arduino/sketches/CF768F34FC47A0606F882E35BAFB02FE/sketch/esp32-code.ino.cpp.o:(.literal._Z5setupv+0xc0): undefined reference to `rclc_subscription_init_default'
$HOME/Library/Arduino15/packages/esp32/tools/esp-x32/2507/bin/../lib/gcc/xtensa-esp-elf/14.2.0/../../../../xtensa-esp-elf/bin/ld: $HOME/Library/Caches/arduino/sketches/CF768F34FC47A0606F882E35BAFB02FE/sketch/esp32-code.ino.cpp.o:(.literal._Z5setupv+0xc4): undefined reference to `rosidl_typesupport_c__get_message_type_support_handle__std_msgs__msg__Int32'
$HOME/Library/Arduino15/packages/esp32/tools/esp-x32/2507/bin/../lib/gcc/xtensa-esp-elf/14.2.0/../../../../xtensa-esp-elf/bin/ld: $HOME/Library/Caches/arduino/sketches/CF768F34FC47A0606F882E35BAFB02FE/sketch/esp32-code.ino.cpp.o:(.literal._Z5setupv+0xc8): undefined reference to `std_msgs__msg__Int32__init'
$HOME/Library/Arduino15/packages/esp32/tools/esp-x32/2507/bin/../lib/gcc/xtensa-esp-elf/14.2.0/../../../../xtensa-esp-elf/bin/ld: $HOME/Library/Caches/arduino/sketches/CF768F34FC47A0606F882E35BAFB02FE/sketch/esp32-code.ino.cpp.o:(.literal._Z5setupv+0xcc): undefined reference to `rosidl_typesupport_c__get_message_type_support_handle__std_msgs__msg__UInt16'
$HOME/Library/Arduino15/packages/esp32/tools/esp-x32/2507/bin/../lib/gcc/xtensa-esp-elf/14.2.0/../../../../xtensa-esp-elf/bin/ld: $HOME/Library/Caches/arduino/sketches/CF768F34FC47A0606F882E35BAFB02FE/sketch/esp32-code.ino.cpp.o:(.literal._Z5setupv+0xd0): undefined reference to `std_msgs__msg__UInt16__init'
$HOME/Library/Arduino15/packages/esp32/tools/esp-x32/2507/bin/../lib/gcc/xtensa-esp-elf/14.2.0/../../../../xtensa-esp-elf/bin/ld: $HOME/Library/Caches/arduino/sketches/CF768F34FC47A0606F882E35BAFB02FE/sketch/esp32-code.ino.cpp.o:(.literal._Z5setupv+0xd4): undefined reference to `rclc_timer_init_default'
$HOME/Library/Arduino15/packages/esp32/tools/esp-x32/2507/bin/../lib/gcc/xtensa-esp-elf/14.2.0/../../../../xtensa-esp-elf/bin/ld: $HOME/Library/Caches/arduino/sketches/CF768F34FC47A0606F882E35BAFB02FE/sketch/esp32-code.ino.cpp.o:(.literal._Z5setupv+0xd8): undefined reference to `rclc_executor_init'
$HOME/Library/Arduino15/packages/esp32/tools/esp-x32/2507/bin/../lib/gcc/xtensa-esp-elf/14.2.0/../../../../xtensa-esp-elf/bin/ld: $HOME/Library/Caches/arduino/sketches/CF768F34FC47A0606F882E35BAFB02FE/sketch/esp32-code.ino.cpp.o:(.literal._Z5setupv+0xdc): undefined reference to `rclc_executor_add_subscription'
$HOME/Library/Arduino15/packages/esp32/tools/esp-x32/2507/bin/../lib/gcc/xtensa-esp-elf/14.2.0/../../../../xtensa-esp-elf/bin/ld: $HOME/Library/Caches/arduino/sketches/CF768F34FC47A0606F882E35BAFB02FE/sketch/esp32-code.ino.cpp.o:(.literal._Z5setupv+0xe0): undefined reference to `rclc_executor_add_timer'
$HOME/Library/Arduino15/packages/esp32/tools/esp-x32/2507/bin/../lib/gcc/xtensa-esp-elf/14.2.0/../../../../xtensa-esp-elf/bin/ld: $HOME/Library/Caches/arduino/sketches/CF768F34FC47A0606F882E35BAFB02FE/sketch/esp32-code.ino.cpp.o: in function `_Z12publish_textPKcb':
$HOME/Documents/test/robot/doc/newcode/esp32-code/esp32-code.ino:72:(.text._Z12publish_textPKcb+0x4c): undefined reference to `rcl_publish'
$HOME/Library/Arduino15/packages/esp32/tools/esp-x32/2507/bin/../lib/gcc/xtensa-esp-elf/14.2.0/../../../../xtensa-esp-elf/bin/ld: $HOME/Documents/test/robot/doc/newcode/esp32-code/esp32-code.ino:74:(.text._Z12publish_textPKcb+0x84): undefined reference to `rcl_publish'
$HOME/Library/Arduino15/packages/esp32/tools/esp-x32/2507/bin/../lib/gcc/xtensa-esp-elf/14.2.0/../../../../xtensa-esp-elf/bin/ld: $HOME/Library/Caches/arduino/sketches/CF768F34FC47A0606F882E35BAFB02FE/sketch/esp32-code.ino.cpp.o: in function `_Z15publish_encodert':
$HOME/Documents/test/robot/doc/newcode/esp32-code/esp32-code.ino:215:(.text._Z15publish_encodert+0x1d): undefined reference to `rcl_publish'
$HOME/Library/Arduino15/packages/esp32/tools/esp-x32/2507/bin/../lib/gcc/xtensa-esp-elf/14.2.0/../../../../xtensa-esp-elf/bin/ld: $HOME/Library/Caches/arduino/sketches/CF768F34FC47A0606F882E35BAFB02FE/sketch/esp32-code.ino.cpp.o: in function `_Z4loopv':
$HOME/Documents/test/robot/doc/newcode/esp32-code/esp32-code.ino:365:(.text._Z4loopv+0x20): undefined reference to `rclc_executor_spin_some'
$HOME/Library/Arduino15/packages/esp32/tools/esp-x32/2507/bin/../lib/gcc/xtensa-esp-elf/14.2.0/../../../../xtensa-esp-elf/bin/ld: $HOME/Library/Caches/arduino/sketches/CF768F34FC47A0606F882E35BAFB02FE/sketch/esp32-code.ino.cpp.o: in function `_Z5setupv':
$HOME/Documents/Arduino/libraries/micro_ros_arduino/src/micro_ros_arduino.h:147:(.text._Z5setupv+0xae): undefined reference to `rmw_uros_set_custom_transport'
$HOME/Library/Arduino15/packages/esp32/tools/esp-x32/2507/bin/../lib/gcc/xtensa-esp-elf/14.2.0/../../../../xtensa-esp-elf/bin/ld: $HOME/Library/Caches/arduino/sketches/CF768F34FC47A0606F882E35BAFB02FE/sketch/esp32-code.ino.cpp.o: in function `_Z5setupv':
$HOME/Documents/test/robot/doc/newcode/esp32-code/esp32-code.ino:273:(.text._Z5setupv+0xbf): undefined reference to `rcutils_get_default_allocator'
$HOME/Library/Arduino15/packages/esp32/tools/esp-x32/2507/bin/../lib/gcc/xtensa-esp-elf/14.2.0/../../../../xtensa-esp-elf/bin/ld: $HOME/Documents/test/robot/doc/newcode/esp32-code/esp32-code.ino:276:(.text._Z5setupv+0xe0): undefined reference to `rclc_support_init'
$HOME/Library/Arduino15/packages/esp32/tools/esp-x32/2507/bin/../lib/gcc/xtensa-esp-elf/14.2.0/../../../../xtensa-esp-elf/bin/ld: $HOME/Documents/test/robot/doc/newcode/esp32-code/esp32-code.ino:279:(.text._Z5setupv+0x148): undefined reference to `rclc_node_init_default'
$HOME/Library/Arduino15/packages/esp32/tools/esp-x32/2507/bin/../lib/gcc/xtensa-esp-elf/14.2.0/../../../../xtensa-esp-elf/bin/ld: $HOME/Documents/test/robot/doc/newcode/esp32-code/esp32-code.ino:282:(.text._Z5setupv+0x156): undefined reference to `rosidl_typesupport_c__get_message_type_support_handle__std_msgs__msg__String'
$HOME/Library/Arduino15/packages/esp32/tools/esp-x32/2507/bin/../lib/gcc/xtensa-esp-elf/14.2.0/../../../../xtensa-esp-elf/bin/ld: $HOME/Documents/test/robot/doc/newcode/esp32-code/esp32-code.ino:282:(.text._Z5setupv+0x166): undefined reference to `rclc_publisher_init_default'
$HOME/Library/Arduino15/packages/esp32/tools/esp-x32/2507/bin/../lib/gcc/xtensa-esp-elf/14.2.0/../../../../xtensa-esp-elf/bin/ld: $HOME/Documents/test/robot/doc/newcode/esp32-code/esp32-code.ino:287:(.text._Z5setupv+0x17b): undefined reference to `std_msgs__msg__String__init'
$HOME/Library/Arduino15/packages/esp32/tools/esp-x32/2507/bin/../lib/gcc/xtensa-esp-elf/14.2.0/../../../../xtensa-esp-elf/bin/ld: $HOME/Documents/test/robot/doc/newcode/esp32-code/esp32-code.ino:294:(.text._Z5setupv+0x194): undefined reference to `rosidl_typesupport_c__get_message_type_support_handle__std_msgs__msg__String'
$HOME/Library/Arduino15/packages/esp32/tools/esp-x32/2507/bin/../lib/gcc/xtensa-esp-elf/14.2.0/../../../../xtensa-esp-elf/bin/ld: $HOME/Documents/test/robot/doc/newcode/esp32-code/esp32-code.ino:294:(.text._Z5setupv+0x1a4): undefined reference to `rclc_subscription_init_default'
$HOME/Library/Arduino15/packages/esp32/tools/esp-x32/2507/bin/../lib/gcc/xtensa-esp-elf/14.2.0/../../../../xtensa-esp-elf/bin/ld: $HOME/Documents/test/robot/doc/newcode/esp32-code/esp32-code.ino:299:(.text._Z5setupv+0x1ba): undefined reference to `std_msgs__msg__String__init'
$HOME/Library/Arduino15/packages/esp32/tools/esp-x32/2507/bin/../lib/gcc/xtensa-esp-elf/14.2.0/../../../../xtensa-esp-elf/bin/ld: $HOME/Documents/test/robot/doc/newcode/esp32-code/esp32-code.ino:305:(.text._Z5setupv+0x1d2): undefined reference to `rosidl_typesupport_c__get_message_type_support_handle__std_msgs__msg__Int32'
$HOME/Library/Arduino15/packages/esp32/tools/esp-x32/2507/bin/../lib/gcc/xtensa-esp-elf/14.2.0/../../../../xtensa-esp-elf/bin/ld: $HOME/Documents/test/robot/doc/newcode/esp32-code/esp32-code.ino:305:(.text._Z5setupv+0x1e2): undefined reference to `rclc_subscription_init_default'
$HOME/Library/Arduino15/packages/esp32/tools/esp-x32/2507/bin/../lib/gcc/xtensa-esp-elf/14.2.0/../../../../xtensa-esp-elf/bin/ld: $HOME/Documents/test/robot/doc/newcode/esp32-code/esp32-code.ino:310:(.text._Z5setupv+0x1f3): undefined reference to `std_msgs__msg__Int32__init'
$HOME/Library/Arduino15/packages/esp32/tools/esp-x32/2507/bin/../lib/gcc/xtensa-esp-elf/14.2.0/../../../../xtensa-esp-elf/bin/ld: $HOME/Documents/test/robot/doc/newcode/esp32-code/esp32-code.ino:313:(.text._Z5setupv+0x1f9): undefined reference to `rosidl_typesupport_c__get_message_type_support_handle__std_msgs__msg__UInt16'
$HOME/Library/Arduino15/packages/esp32/tools/esp-x32/2507/bin/../lib/gcc/xtensa-esp-elf/14.2.0/../../../../xtensa-esp-elf/bin/ld: $HOME/Documents/test/robot/doc/newcode/esp32-code/esp32-code.ino:313:(.text._Z5setupv+0x20a): undefined reference to `rclc_publisher_init_default'
$HOME/Library/Arduino15/packages/esp32/tools/esp-x32/2507/bin/../lib/gcc/xtensa-esp-elf/14.2.0/../../../../xtensa-esp-elf/bin/ld: $HOME/Documents/test/robot/doc/newcode/esp32-code/esp32-code.ino:318:(.text._Z5setupv+0x21b): undefined reference to `std_msgs__msg__UInt16__init'
$HOME/Library/Arduino15/packages/esp32/tools/esp-x32/2507/bin/../lib/gcc/xtensa-esp-elf/14.2.0/../../../../xtensa-esp-elf/bin/ld: $HOME/Documents/test/robot/doc/newcode/esp32-code/esp32-code.ino:321:(.text._Z5setupv+0x221): undefined reference to `rosidl_typesupport_c__get_message_type_support_handle__std_msgs__msg__Int32'
$HOME/Library/Arduino15/packages/esp32/tools/esp-x32/2507/bin/../lib/gcc/xtensa-esp-elf/14.2.0/../../../../xtensa-esp-elf/bin/ld: $HOME/Documents/test/robot/doc/newcode/esp32-code/esp32-code.ino:321:(.text._Z5setupv+0x232): undefined reference to `rclc_subscription_init_default'
$HOME/Library/Arduino15/packages/esp32/tools/esp-x32/2507/bin/../lib/gcc/xtensa-esp-elf/14.2.0/../../../../xtensa-esp-elf/bin/ld: $HOME/Documents/test/robot/doc/newcode/esp32-code/esp32-code.ino:326:(.text._Z5setupv+0x243): undefined reference to `std_msgs__msg__Int32__init'
$HOME/Library/Arduino15/packages/esp32/tools/esp-x32/2507/bin/../lib/gcc/xtensa-esp-elf/14.2.0/../../../../xtensa-esp-elf/bin/ld: $HOME/Documents/test/robot/doc/newcode/esp32-code/esp32-code.ino:330:(.text._Z5setupv+0x257): undefined reference to `rclc_timer_init_default'
$HOME/Library/Arduino15/packages/esp32/tools/esp-x32/2507/bin/../lib/gcc/xtensa-esp-elf/14.2.0/../../../../xtensa-esp-elf/bin/ld: $HOME/Documents/test/robot/doc/newcode/esp32-code/esp32-code.ino:337:(.text._Z5setupv+0x272): undefined reference to `rclc_timer_init_default'
$HOME/Library/Arduino15/packages/esp32/tools/esp-x32/2507/bin/../lib/gcc/xtensa-esp-elf/14.2.0/../../../../xtensa-esp-elf/bin/ld: $HOME/Documents/test/robot/doc/newcode/esp32-code/esp32-code.ino:345:(.text._Z5setupv+0x28c): undefined reference to `rclc_executor_init'
$HOME/Library/Arduino15/packages/esp32/tools/esp-x32/2507/bin/../lib/gcc/xtensa-esp-elf/14.2.0/../../../../xtensa-esp-elf/bin/ld: $HOME/Documents/test/robot/doc/newcode/esp32-code/esp32-code.ino:349:(.text._Z5setupv+0x2a8): undefined reference to `rclc_executor_add_subscription'
$HOME/Library/Arduino15/packages/esp32/tools/esp-x32/2507/bin/../lib/gcc/xtensa-esp-elf/14.2.0/../../../../xtensa-esp-elf/bin/ld: $HOME/Documents/test/robot/doc/newcode/esp32-code/esp32-code.ino:352:(.text._Z5setupv+0x2c4): undefined reference to `rclc_executor_add_subscription'
$HOME/Library/Arduino15/packages/esp32/tools/esp-x32/2507/bin/../lib/gcc/xtensa-esp-elf/14.2.0/../../../../xtensa-esp-elf/bin/ld: $HOME/Documents/test/robot/doc/newcode/esp32-code/esp32-code.ino:355:(.text._Z5setupv+0x2e0): undefined reference to `rclc_executor_add_subscription'
$HOME/Library/Arduino15/packages/esp32/tools/esp-x32/2507/bin/../lib/gcc/xtensa-esp-elf/14.2.0/../../../../xtensa-esp-elf/bin/ld: $HOME/Documents/test/robot/doc/newcode/esp32-code/esp32-code.ino:357:(.text._Z5setupv+0x2f3): undefined reference to `rclc_executor_add_timer'
$HOME/Library/Arduino15/packages/esp32/tools/esp-x32/2507/bin/../lib/gcc/xtensa-esp-elf/14.2.0/../../../../xtensa-esp-elf/bin/ld: $HOME/Documents/test/robot/doc/newcode/esp32-code/esp32-code.ino:360:(.text._Z5setupv+0x306): undefined reference to `rclc_executor_add_timer'
collect2: error: ld returned 1 exit status
exit status 1

Compilation error: exit status 1
```

### Path the micro_ros library at Arduino Libary
how to resolve arduino **undefined reference** issue

The actual error is:

`Precompiled library in "$HOME/Documents/Arduino/libraries/micro_ros_arduino/src/esp32s3" not found`

```
<team-user>@<jetson-host> Arduino % ls $HOME/Documents/Arduino/libraries/micro_ros_arduino/src/esp32/
libmicroros.a
<team-user>@<jetson-host> Arduino %

cd $HOME/Documents/Arduino/libraries/micro_ros_arduino/src

cp -pa esp32 esp32s3

<team-user>@<jetson-host> Arduino % cd $HOME/Documents/Arduino/libraries/micro_ros_arduino/src/
<team-user>@<jetson-host> src % cp -pa esp32 esp32s3
<team-user>@<jetson-host> src % ls -ld esp32s3
drwxr-xr-x  3 <local-user>  staff  96 22 Nov 14:47 esp32s3
<team-user>@<jetson-host> src % ls -ld esp32
drwxr-xr-x  3 <local-user>  staff  96 22 Nov 14:47 esp32
<team-user>@<jetson-host> src % ls -l esp32s3
total 27640
-rwxr-xr-x  1 <local-user>  staff  141486
```



### Verify Code again



No error show up, below is the output:

```
Library micro_ros_arduino has been declared precompiled:
Using precompiled library in $HOME/Documents/Arduino/libraries/micro_ros_arduino/src/esp32s3
Sketch uses 1247295 bytes (95%) of program storage space. Maximum is 1310720 bytes.
Global variables use 73000 bytes (22%) of dynamic memory, leaving 254680 bytes for local variables. Maximum is 327680 bytes.
```

### Upload Code (Flash)





### If you face issue: : Failed to connect to ESP32-S3: No serial data received.
**Then your esp32s3 needs to enter the bootloader mode (download mode)**

Hold down the BOOT button and then pressing and release RESET button while still holding the BOOT button

IMPORTANT NOTE: First time you try to upload the code to the board you purchased, you might see this error:

`A fatal error occurred: Failed to connect to ESP32-S3: No serial data received.`

The solution for this problem is to hold down the BOOT button and then pressing and release RESET button while still holding the BOOT button. This will initiate Firmware Download mode, and you only need to do it once.

Some tutorials suggest that you should hold BOOT button while uploading the code. However, this is not necessary in Arduino IDE (at least not for the board we are using).

### Arduino IDE upload code (flash esp32s3) output history:
```
Library micro_ros_arduino has been declared precompiled:
Using precompiled library in $HOME/Documents/Arduino/libraries/micro_ros_arduino/src/esp32s3
Sketch uses 1247295 bytes (95%) of program storage space. Maximum is 1310720 bytes.
Global variables use 73000 bytes (22%) of dynamic memory, leaving 254680 bytes for local variables. Maximum is 327680 bytes.
esptool v5.1.0
Serial port /dev/cu.usbmodem1101:
Connecting...
Connected to ESP32-S3 on /dev/cu.usbmodem1101:
Chip type:          ESP32-S3 (QFN56) (revision v0.1)
Features:           Wi-Fi, BT 5 (LE), Dual Core + LP Core, 240MHz, Embedded PSRAM 8MB (AP_3v3)
Crystal frequency:  40MHz
USB mode:           USB-Serial/JTAG
MAC:                f4:12:fa:fd:93:d8

Uploading stub flasher...
Running stub flasher...
Stub flasher running.
Changing baud rate to 921600...
Changed.

Configuring flash size...
Flash will be erased from 0x00000000 to 0x00004fff...
Flash will be erased from 0x00008000 to 0x00008fff...
Flash will be erased from 0x0000e000 to 0x0000ffff...
Flash will be erased from 0x00010000 to 0x00140fff...
Compressed 20224 bytes to 13061...

Writing at 0x00000000 [                              ]   0.0% 0/13061 bytes...

Writing at 0x00004f00 [==============================] 100.0% 13061/13061 bytes...
Wrote 20224 bytes (13061 compressed) at 0x00000000 in 0.4 seconds (419.1 kbit/s).
Hash of data verified.
Compressed 3072 bytes to 146...

Writing at 0x00008000 [                              ]   0.0% 0/146 bytes...

Writing at 0x00008c00 [==============================] 100.0% 146/146 bytes...
Wrote 3072 bytes (146 compressed) at 0x00008000 in 0.1 seconds (390.2 kbit/s).
Hash of data verified.
Compressed 8192 bytes to 47...

Writing at 0x0000e000 [                              ]   0.0% 0/47 bytes...

Writing at 0x00010000 [==============================] 100.0% 47/47 bytes...
Wrote 8192 bytes (47 compressed) at 0x0000e000 in 0.1 seconds (590.2 kbit/s).
Hash of data verified.
Compressed 1247440 bytes to 754162...

Writing at 0x00010000 [                              ]   0.0% 0/754162 bytes...

Writing at 0x0001c313 [                              ]   2.2% 16384/754162 bytes...

Writing at 0x00027826 [>                             ]   4.3% 32768/754162 bytes...

Writing at 0x0002f6c5 [>                             ]   6.5% 49152/754162 bytes...

Writing at 0x000420e0 [=>                            ]   8.7% 65536/754162 bytes...

Writing at 0x0004e861 [==>                           ]  10.9% 81920/754162 bytes...

Writing at 0x000544dc [==>                           ]  13.0% 98304/754162 bytes...

Writing at 0x00059bc8 [===>                          ]  15.2% 114688/754162 bytes...

Writing at 0x0005f73d [====>                         ]  17.4% 131072/754162 bytes...

Writing at 0x00065119 [====>                         ]  19.6% 147456/754162 bytes...

Writing at 0x0006ab22 [=====>                        ]  21.7% 163840/754162 bytes...

Writing at 0x0006faf6 [======>                       ]  23.9% 180224/754162 bytes...

Writing at 0x00074ec9 [======>                       ]  26.1% 196608/754162 bytes...

Writing at 0x0007a269 [=======>                      ]  28.2% 212992/754162 bytes...

Writing at 0x0007f629 [========>                     ]  30.4% 229376/754162 bytes...

Writing at 0x00084f7b [========>                     ]  32.6% 245760/754162 bytes...

Writing at 0x0008a144 [=========>                    ]  34.8% 262144/754162 bytes...

Writing at 0x0008f540 [==========>                   ]  36.9% 278528/754162 bytes...

Writing at 0x00094d6b [==========>                   ]  39.1% 294912/754162 bytes...

Writing at 0x0009a74d [===========>                  ]  41.3% 311296/754162 bytes...

Writing at 0x0009fed5 [============>                 ]  43.4% 327680/754162 bytes...

Writing at 0x000a53ce [============>                 ]  45.6% 344064/754162 bytes...

Writing at 0x000aa9b5 [=============>                ]  47.8% 360448/754162 bytes...

Writing at 0x000afbd2 [=============>                ]  50.0% 376832/754162 bytes...

Writing at 0x000b4fb6 [==============>               ]  52.1% 393216/754162 bytes...

Writing at 0x000ba792 [===============>              ]  54.3% 409600/754162 bytes...

Writing at 0x000bfd46 [===============>              ]  56.5% 425984/754162 bytes...

Writing at 0x000c524a [================>             ]  58.7% 442368/754162 bytes...

Writing at 0x000ca5c0 [=================>            ]  60.8% 458752/754162 bytes...

Writing at 0x000cfd37 [=================>            ]  63.0% 475136/754162 bytes...

Writing at 0x000d69c4 [==================>           ]  65.2% 491520/754162 bytes...

Writing at 0x000deae9 [===================>          ]  67.3% 507904/754162 bytes...

Writing at 0x000e67a8 [===================>          ]  69.5% 524288/754162 bytes...

Writing at 0x000eec05 [====================>         ]  71.7% 540672/754162 bytes...

Writing at 0x000f50d4 [=====================>        ]  73.9% 557056/754162 bytes...

Writing at 0x000fa461 [=====================>        ]  76.0% 573440/754162 bytes...

Writing at 0x001008e9 [======================>       ]  78.2% 589824/754162 bytes...

Writing at 0x00105ea6 [=======================>      ]  80.4% 606208/754162 bytes...

Writing at 0x0010b6df [=======================>      ]  82.6% 622592/754162 bytes...

Writing at 0x001131f0 [========================>     ]  84.7% 638976/754162 bytes...

Writing at 0x0011c34f [=========================>    ]  86.9% 655360/754162 bytes...

Writing at 0x00123b57 [=========================>    ]  89.1% 671744/754162 bytes...

Writing at 0x00128c33 [==========================>   ]  91.2% 688128/754162 bytes...

Writing at 0x0012e70c [===========================>  ]  93.4% 704512/754162 bytes...

Writing at 0x001347ba [===========================>  ]  95.6% 720896/754162 bytes...

Writing at 0x0013a3f0 [============================> ]  97.8% 737280/754162 bytes...

Writing at 0x0014064b [============================> ]  99.9% 753664/754162 bytes...

Writing at 0x001408d0 [==============================] 100.0% 754162/754162 bytes...
Wrote 1247440 bytes (754162 compressed) at 0x00010000 in 9.8 seconds (1014.4 kbit/s).
Hash of data verified.

Hard resetting via RTS pin...
```

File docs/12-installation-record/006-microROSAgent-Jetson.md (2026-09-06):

# How to run a micro-ROS agent in ROS 2 Humble that will display the messages sent from an esp32s3 on the computer screen.

## Jetson / linux run MicroROSAgent
https://micro.ros.org/docs/tutorials/core/first_application_linux/

Source the ROS 2 installation
```
/opt/ros/humble/setup.bash
```

### Create a workspace and download the micro-ROS tools
#### mkdir at your home folder so it is ~/microros_ws
```
mkdir ~/microros_ws
cd ~/microros_ws
git clone -b $ROS_DISTRO https://github.com/micro-ROS/micro_ros_setup.git src/micro_ros_setup
```

### Update jetson dependencies using apt
#### run as user <team-github-account>
```
sudo apt update
sudo apt install -y python3-rosdep
```

### Update dependencies using rosdep
```
sudo rosdep init
sudo rosdep update
rosdep update
rosdep install --from-paths src --ignore-src -y
```

### test colcon
```
sudo apt install python3-colcon-common-extensions
colcon --help
```

### Install pip
```
sudo apt-get install python3-pip
```

### Build micro-ROS tools and source them
```
colcon build
source install/local_setup.bash

sudo chown -R <team-github-account>:<team-github-account> ~/microros_ws
```

### error:
`AttributeError: module 'em' has no attribute 'BUFFERED_OPT'`

make sure empy version is 3.3.4

```
<team-user>@<jetson-host>:~/microros_ws/src/micro_ros_setup$ which -a pip3
$HOME/.espressif/python_env/idf5.4_py3.10_env/bin/pip3

pip3 install empy==3.3.4

pip3 install catkin_pkg empy lark-parser colcon-common-extensions
```

### sourcing the ROS 2 and micro-ROS environment

```
cd ~/microros_ws/
/opt/ros/humble/setup.bash
source install/local_setup.bash
```

### Download micro-ROS-Agent packages
```
sudo apt install python3-vcstool
ros2 run micro_ros_setup create_agent_ws.sh
```

### Build step
```
ros2 run micro_ros_setup build_agent.sh
source install/local_setup.bash

Building micro-ROS Agent
Starting >>> micro_ros_msgs
Finished <<< micro_ros_msgs [9.35s]
Starting >>> micro_ros_agent
[Processing: micro_ros_agent]
[Processing: micro_ros_agent]
--- stderr: micro_ros_agent
Cloning into 'xrceagent'...
HEAD is now at 57d0862 Release v2.4.2
CMake Warning (dev) at /usr/share/cmake-3.22/Modules/FindPackageHandleStandardArgs.cmake:438 (message):
  The package name passed to `find_package_handle_standard_args` (tinyxml2)
  does not match the name of the calling package (TinyXML2).  This can lead
  to problems in calling code that expects `find_package` result variables
  (e.g., `_FOUND`) to follow a certain pattern.
Call Stack (most recent call first):
  cmake/modules/FindTinyXML2.cmake:40 (find_package_handle_standard_args)
  /opt/ros/humble/share/fastrtps/cmake/fastrtps-config.cmake:51 (find_package)
  CMakeLists.txt:153 (find_package)
This warning is for project developers.  Use -Wno-dev to suppress it.

---
Finished <<< micro_ros_agent [1min 28s]

Summary: 2 packages finished [1min 38s]
  1 package had stderr output: micro_ros_agent
```

#### Add micro-ROS environment to bashrc (optional):

You can add the ROS 2 and micro-ROS workspace setup files to your .bashrc so the files do not have to be sourced every time a new command line is opened.

```
echo source /opt/ros/$ROS_DISTRO/setup.bash >> ~/.bashrc
echo source ~/microros_ws/install/local_setup.bash >> ~/.bashrc
```

###  Launch MicroROSAgent and check that a message is received
Before you do ros2 run micro_ros_agent, please make sure the `008-add-module-config-eth-user-group.md` you already setup. Because we use eth to connect jetson to esp32.

Also please make sure the Dupont wires are connected correctly and firmly. If the Dupont connections are loose, the signal may not be transmitted properly, which can prevent the Jetson micro_ros_agent from receiving a response from the ESP32, and you will not see any ROS2 /microROS topics.**

```
cd ~/microros_ws
export ROS_DOMAIN_ID=30
export XRCE_DOMAIN_ID_OVERRIDE=30
source /opt/ros/humble/setup.bash
source install/local_setup.bash
ros2 run micro_ros_agent micro_ros_agent udp4 --port 8888
```

```
<team-user>@<jetson-host>:~/microros_ws$ ros2 run micro_ros_agent micro_ros_agent udp4 --port 8888
[1763168192.371777] info     | UDPv4AgentLinux.cpp | init                     | running...             | port: 8888
[1763168192.374619] info     | Root.cpp           | set_verbose_level        | logger setup           | verbose_level: 4
```

at the end of 005, we see upload code (flash) last output: Hard resetting via RTS pin...
so we need to reset esp32s3



Press the reset button on the esp32s3.

`cd ~/microros_ws/`

### Source the ROS 2 installation
`source /opt/ros/humble/setup.bash`

### Source the MicroROS installation
`source install/local_setup.bash`

### Check the current ROS2 topic
Run `ros2 topic list`

```
ros2 topic list

Below is the ROS2 Topics for esp32s3 microROS:
/microROS/audio_play
/microROS/encoder_data
/microROS/motor_control
/microROS/oled_display
/microROS/servo_control
/microROS/status
/odometry/filtered
```

### Test DC Motor move
Source ROS 2 first:
```bash
source /opt/ros/humble/setup.bash
```

Publish motor commands continuously. This is required for firmware versions with the motor command watchdog.

Eg.
```bash
To go forward:
ros2 topic pub -r 10 /microROS/motor_control std_msgs/msg/Int32 "{data: 100}"
To stop:
ros2 topic pub --once /microROS/motor_control std_msgs/msg/Int32 "{data: 0}"
To reverse:
ros2 topic pub -r 10 /microROS/motor_control std_msgs/msg/Int32 "{data: -100}"
```

### Test Servo Motor
Source ROS 2 first:
```bash
source /opt/ros/humble/setup.bash
```

To control the servo, publish one command. Negative is left, positive is right.

Eg.
```bash
ros2 topic pub --once /microROS/servo_control std_msgs/msg/Int32 "{data: -200}"
ros2 topic pub --once /microROS/servo_control std_msgs/msg/Int32 "{data: 200}"
ros2 topic pub --once /microROS/servo_control std_msgs/msg/Int32 "{data: 0}"
ros2 topic pub --once /microROS/servo_control std_msgs/msg/Int32 "{data: 500}"
ros2 topic pub --once /microROS/servo_control std_msgs/msg/Int32 "{data: 0}"
```

### Test OLED Display:
To control the display:

Prints text to the screen:

`ros2 topic pub -1 /microROS/oled_display std_msgs/msg/String 'data: "print <x> <y> <text>"'`

Clears the screen:

`ros2 topic pub -1 /microROS/oled_display std_msgs/msg/String 'data: "clear"'`

Clears an area of the screen:

`ros2 topic pub -1 /microROS/oled_display std_msgs/msg/String 'data: "clear <x> <y> <w> <h>"'`

Updates the screen with all the changes applied by the previous command:

`ros2 topic pub -1 /microROS/oled_display std_msgs/msg/String 'data: "update"'`

You can combine commands with "\n" (The newline character):

`ros2 topic pub -1 /microROS/oled_display std_msgs/msg/String 'data: "clear \n print 20 20 hello world \n update"'`

### Test ESP32S3 Status (Display the current voltage and remaining battery capacity):
To display the status stream:

`ros2 topic echo /microROS/status`



### Test Speaker:

### Default beep tone

`ros2 topic pub -1 /microROS/audio_play std_msgs/msg/Int32MultiArray "{data: [660, 500]}"`

output
```
publisher: beginning loop
publishing #1: std_msgs.msg.Int32MultiArray(layout=std_msgs.msg.MultiArrayLayout(dim=[], data_offset=0), data=[660, 500])
```

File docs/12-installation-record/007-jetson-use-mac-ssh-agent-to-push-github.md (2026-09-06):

# Flow
```
MacBook (Have GitHub SSH key)
        │
        │ ssh -A
        ▼
Jetson (No key)
        │
        ▼
GitHub
```

# Mac config
## mark sure macbook key can access github
```
ssh -T git@github.com
```
### if succ you will see below message
```
Hi <team-github-account>! You've successfully authenticated, but GitHub does not provide shell access.
```
## confirm key in ssh-agent
```
ssh-add -l
```
```
<team-user>@<jetson-host> ~ % ssh-add -l
The agent has no identities.
```
### if key is not in ssh-agent, added
```
ssh-add ~/.ssh/id_rsa
```
```
<team-user>@<jetson-host> ~ % ssh-add ~/.ssh/id_rsa
Identity added: $HOME/.ssh/id_rsa (lily_wang1983000@cs-553581357317-default)
```
# mac login jetson
**-A means Agent Forwarding**
```
ssh -A <team-user>@<jetson-host>
```
## check jetson env setting
```
echo $SSH_AUTH_SOCK
```
### if you see below, then it succ
```
<team-user>@<jetson-host>:~$ echo $SSH_AUTH_SOCK
/tmp/ssh-XXXXLG1vwF/agent.6884
```
# Jetson testing
## test jetson can access github without setting local ssh key
```
ssh -T git@github.com
```
### if agent forwarding succ, then it will display:
```
Hi <team-github-account>! You've successfully authenticated, but GitHub does not provide shell access.
```

## pull test
```
<team-user>@<jetson-host>:~/wro_ign_gazebo_sim$ git pull origin main
remote: Enumerating objects: 45, done.
remote: Counting objects: 100% (45/45), done.
remote: Compressing objects: 100% (19/19), done.
remote: Total 35 (delta 19), reused 28 (delta 12), pack-reused 0 (from 0)
Unpacking objects: 100% (35/35), 6.28 KiB | 279.00 KiB/s, done.
From github.com:<team-github-account>/wro_ign_gazebo_sim
 * branch            main       -> FETCH_HEAD
   ae67267..d346e50  main       -> origin/main
Updating ae67267..d346e50
Fast-forward
 hiway_bringup_backup/bring-up-all-step.md                          |  67 +++++++++++++++++++++++++++++++++++++++++++++++++++++++++
 hiway_bringup_backup/how-to-run-bringup.md                         |  23 ++++++++++++++++++++
 hiway_bringup_backup/launch/sensors.launch.py                      | 154 ++++++++++++++++++++++++++++++++++++++++++++++++++++++++++++++++++++++++++++++++++++++++++++++++++++++++++++++++++++++++++++++++++
 hiway_bringup_backup/scripts/setup_ros_env.sh                      |  27 +++++++++++++++++++++++
 hiway_description/.DS_Store                                        | Bin 6148 -> 6148 bytes
 hiway_description/how-to-config-robot-localization.md              | 103 ---------------------------------------------------------------------------------------
 hiway_description/how-to-run-jetson.md                             |  74 ++-------------------------------------------------------------
 hiway_description/how-to-run-rtabmap-slam.md                       |  58 +++++++++++++++++++++++++++++++++++++++++++++++++
 hiway_description/how-to-run-windows-wsl.md                        |  10 ++++-----
 hiway_description/urdf/hiway.urdf.xacro                            |  32 ++++++++++++++++++++-------
 localization/config/ekf.yaml                                       |  16 ++++++++------
 localization/how-to-config-robot-localization.md                   | 157 +++++++++++++++++++++++++++++++++++++++++++++++++++++++++++++++++++++++++++++++++++++++++++++++++++++++++++++++++++++++++++++++++++++
 {hiway_description => localization}/robot-localization-diagram.png | Bin
 13 files changed, 527 insertions(+), 194 deletions(-)
 create mode 100644 hiway_bringup_backup/bring-up-all-step.md
 create mode 100644 hiway_bringup_backup/how-to-run-bringup.md
 create mode 100644 hiway_bringup_backup/launch/sensors.launch.py
 create mode 100644 hiway_bringup_backup/scripts/setup_ros_env.sh
 delete mode 100644 hiway_description/how-to-config-robot-localization.md
 create mode 100644 hiway_description/how-to-run-rtabmap-slam.md
 create mode 100644 localization/how-to-config-robot-localization.md
 rename {hiway_description => localization}/robot-localization-diagram.png (100%)
<team-user>@<jetson-host>:~/wro_ign_gazebo_sim$
```

# All Done!

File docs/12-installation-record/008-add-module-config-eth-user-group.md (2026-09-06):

# Miscellaneous Instructions

## Load 'cp210x' module
Edit /etc/modules and insert this line:
```
# CP210X Driver
cp210x
```

This loads the driver for the LiDAR serial to USB converter.

## Load 'cdc_acm' module
Edit /etc/modules and insert this line:
```
# IMU
cdc_acm
```

## Setup Ethernet
Run `nmcli device status`:
```bash
<team-user>@<jetson-host>:~$ nmcli device status
DEVICE            TYPE      STATE                   CONNECTION
wlP1p1s0          wifi      connected               <...>
docker0           bridge    connected (externally)  docker0
enP8p1s0          ethernet  disconnected            --         <-- Ethernet
p2p-dev-wlP1p1s0  wifi-p2p  disconnected            --
l4tbr0            bridge    unmanaged               --
can0              can       unmanaged               --
usb0              ethernet  unmanaged               --
usb1              ethernet  unmanaged               --
lo                loopback  unmanaged               --
```

Run:
```bash
sudo nmcli con add type ethernet ifname enP8p1s0 con-name eth-static \
  ipv4.method manual ipv4.addresses 192.168.10.1/24
sudo nmcli con up eth-static
```

The command format is:
```bash
sudo nmcli con add type ethernet ifname <ETHERNET_DEVICE> con-name eth-static \
  ipv4.method manual ipv4.addresses <AGENT_IP>/24
```

## Add user to dialout group
```bash
sudo usermod -a -G dialout $USER
```

This allows the user to read/write /dev/ttyX without 'sudo' or 'sudo chmod 777 /dev/ttyX'

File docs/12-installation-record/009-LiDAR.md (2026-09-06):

# LiDAR

**<span style="color:red">Make sure you finished the step 008-misc.md first</span>**

**When wiring the lidar,**

Connect LiDAR TX to *RX*.

Connect LiDAR GND to GND.

Connect LiDAR 5V to 5V.

Reference: <https://github.com/ldrobotSensorTeam/ldlidar_ros2/>

We cloned this repository and adapted it for our project:
https://github.com/AGitUser0001/ldlidar_ros2

**GitHub repository invites have already been sent to all team members.**

## Prepare

```sh
cd ~
mkdir -p ldlidar_ros2_ws/src
cd ldlidar_ros2_ws/src
git clone git@github.com:AGitUser0001/ldlidar_ros2.git
cd ldlidar_ros2
git submodule update --init --recursive
```

```sh
cd ~/ldlidar_ros2_ws/src/ldlidar_ros2
ls launch/*lidar1* launch/*lidar2*
```

make sure you see below 4 files

```
launch/lidar1.launch.py
launch/lidar2.launch.py
launch/viewer_lidar1.launch.py
launch/viewer_lidar2.launch.py
```

### Build:
```sh
cd ~/ldlidar_ros2_ws
source /opt/ros/humble/setup.bash
colcon build
```

#### Some build error and how to resolve:

Below issue is because you forgot to **source ros2**

Error:

```
<team-user>@<jetson-host>:~/ldlidar_ros2_ws$ colcon build
Starting >>> ldlidar_ros2
--- stderr: ldlidar_ros2
CMake Error at CMakeLists.txt:19 (find_package):
  By not providing "Findament_cmake.cmake" in CMAKE_MODULE_PATH this project
  has asked CMake to find a package configuration file provided by
  "ament_cmake", but CMake did not find one.

  Could not find a package configuration file provided by "ament_cmake" with
  any of the following names:

    ament_cmakeConfig.cmake
    ament_cmake-config.cmake

  Add the installation prefix of "ament_cmake" to CMAKE_PREFIX_PATH or set
  "ament_cmake_DIR" to a directory containing one of the above files.  If
  "ament_cmake" provides a separate development package or SDK, be sure it
  has been installed.

---
Failed   <<< ldlidar_ros2 [1.77s, exited with code 1]

Summary: 0 packages finished [2.25s]
  1 package failed: ldlidar_ros2
  1 package had stderr output: ldlidar_ros2
```

Solution:

```sh
source /opt/ros/humble/setup.bash
```

Below issue is because you forgot to **git submodule update --init --recursive**

Error:

```
<team-user>@<jetson-host>:~/ldlidar_ros2_ws$ colcon build
Starting >>> ldlidar_ros2
--- stderr: ldlidar_ros2
CMake Error at CMakeLists.txt:41 (add_subdirectory):
  The source directory

    $HOME/ldlidar_ros2_ws/src/ldlidar_ros2/sdk

  does not contain a CMakeLists.txt file.

---
Failed   <<< ldlidar_ros2 [2.23s, exited with code 1]

Summary: 0 packages finished [2.91s]
  1 package failed: ldlidar_ros2
  1 package had stderr output: ldlidar_ros2
```

Solution:

```sh
cd ldlidar_ros2_ws/src/ldlidar_ros2
git submodule update --init --recursive
```

#### Succ Build output: (warning is acceptable)
```
<team-user>@<jetson-host>:~/ldlidar_ros2_ws$ colcon build
Starting >>> ldlidar_ros2
--- stderr: ldlidar_ros2
In file included from $HOME/ldlidar_ros2_ws/src/ldlidar_ros2/src/demo.cpp:24:
/opt/ros/humble/include/sensor_msgs/sensor_msgs/point_cloud_conversion.hpp:47:6: warning: #warning POINT_CLOUD_DEPRECATION_MESSAGE [-Wcpp]
   47 | #    warning POINT_CLOUD_DEPRECATION_MESSAGE
      |      ^~~~~~~
$HOME/ldlidar_ros2_ws/src/ldlidar_ros2/src/demo.cpp: In function ‘void ToSensorPointCloudMessagePublish(ldlidar::Points2D&, LaserScanSetting&, rclcpp::Node::SharedPtr&, rclcpp::Publisher<sensor_msgs::msg::PointCloud2_<std::allocator<void> > >::SharedPtr&)’:
$HOME/ldlidar_ros2_ws/src/ldlidar_ros2/src/demo.cpp:370:16: warning: ‘bool sensor_msgs::convertPointCloudToPointCloud2(const PointCloud&, sensor_msgs::msg::PointCloud2&)’ is deprecated: PointCloud is deprecated as of Foxy in favor of sensor_msgs/PointCloud2. [-Wdeprecated-declarations]
  370 |   sensor_msgs::convertPointCloudToPointCloud2(output, output_cloud);
      |                ^~~~~~~~~~~~~~~~~~~~~~~~~~~~~~
In file included from $HOME/ldlidar_ros2_ws/src/ldlidar_ros2/src/demo.cpp:24:
/opt/ros/humble/include/sensor_msgs/sensor_msgs/point_cloud_conversion.hpp:81:20: note: declared here
   81 | static inline bool convertPointCloudToPointCloud2(
      |                    ^~~~~~~~~~~~~~~~~~~~~~~~~~~~~~
$HOME/ldlidar_ros2_ws/src/ldlidar_ros2/src/demo.cpp:370:46: warning: ‘bool sensor_msgs::convertPointCloudToPointCloud2(const PointCloud&, sensor_msgs::msg::PointCloud2&)’ is deprecated: PointCloud is deprecated as of Foxy in favor of sensor_msgs/PointCloud2. [-Wdeprecated-declarations]
  370 |   sensor_msgs::convertPointCloudToPointCloud2(output, output_cloud);
      |   ~~~~~~~~~~~~~~~~~~~~~~~~~~~~~~~~~~~~~~~~~~~^~~~~~~~~~~~~~~~~~~~~~
In file included from $HOME/ldlidar_ros2_ws/src/ldlidar_ros2/src/demo.cpp:24:
/opt/ros/humble/include/sensor_msgs/sensor_msgs/point_cloud_conversion.hpp:81:20: note: declared here
   81 | static inline bool convertPointCloudToPointCloud2(
      |                    ^~~~~~~~~~~~~~~~~~~~~~~~~~~~~~
---
Finished <<< ldlidar_ros2 [19.2s]
```

## Run Front Lidar

### Test Launch Front Lidar with Rviz2

Open terminal at GUI

```sh
cd ~/ldlidar_ros2_ws
source /opt/ros/humble/setup.bash
source install/setup.bash
ros2 launch ldlidar_ros2 viewer_lidar1.launch.py
```

The above command will automaticlly launch rviz2 GUI as below:

Launch Front Lidar Default Viewer through rviz2

#### LaserScan View:

Please expand the LaserScan display in the Displays panel on the left side.

Make sure the **Topic** select **/lidar1/scan**

Front Lidar LaserScan Viewer through rviz2

You should see purple dots in the RViz2 GUI. When you or nearby objects move, these dots will move accordingly. The LaserScan points appear larger in size.

#### PointCloud2 View:

Unslect the checkbox next to LaserScan to disable LaserScan Topic

Check the checkbox next to PointCloud2 to enable it.

Please expand the PointCloud2 display in the Displays panel on the left side.

Make sure the **Topic** select **/lidar1/pointcloud2d**

Front Lidar PointCloud2 Viewer through rviz2

You should see purple dots in the RViz2 GUI. When you or nearby objects move, these dots will move accordingly. The PointCloud2 points appear smaller in size.

#### Exit Test
Close the rviz2 GUI, then control + C

## Run Rear Lidar

### Test Launch Rear Lidar with Rviz2

Open terminal at GUI

```sh
cd ~/ldlidar_ros2_ws
source /opt/ros/humble/setup.bash
source install/setup.bash
ros2 launch ldlidar_ros2 viewer_lidar2.launch.py
```

The above command will automaticlly launch rviz2 GUI as below:

Launch Rear Lidar Default Viewer through rviz2

#### LaserScan View:

Please expand the LaserScan display in the Displays panel on the left side.

Make sure the **Topic** select **/lidar2/scan**

Rear Lidar LaserScan Viewer through rviz2

You should see purple dots in the RViz2 GUI. When you or nearby objects move, these dots will move accordingly. The PointCloud2 points appear smaller in size.

#### PointCloud2 View:

Unslect the checkbox next to LaserScan to disable LaserScan Topic

Check the checkbox next to PointCloud2 to enable it.

Please expand the PointCloud2 display in the Displays panel on the left side.

Make sure the **Topic** select **/lidar2/pointcloud2d**

Rear Lidar PointCloud2 Viewer through rviz2

You should see purple dots in the RViz2 GUI. When you or nearby objects move, these dots will move accordingly. The PointCloud2 points appear smaller in size.

#### Exit Test
Close the rviz2 GUI, then control + C

# Laser Merger

## keep 2 Lidar launched

### Launch Front Lidar and Rear Lidar at same terminal

```sh
cd ~/ldlidar_ros2_ws
source /opt/ros/humble/setup.bash
source install/setup.bash
ros2 launch ldlidar_ros2 lidars.launch.py
```

## Prepare Merge
Reference: <https://github.com/pradyum/dual_laser_merger>

```sh
cd ~
mkdir laser_merger_ws/src -p
cd laser_merger_ws/src
git clone -b humble https://github.com/pradyum/dual_laser_merger.git
cd ..
rosdep install --from-paths src --ignore-src -r -y
```

```sh
cd ~/laser_merger_ws/src/dual_laser_merger
```

### Add a file under launch/ called laser_merger_plus_rviz2.launch.py:

```sh
vi launch/laser_merger_plus_rviz2.launch.py
```

#### Paste below content

# real robot merge lidar launch file with rviz2
```py
# Copyright 2024 pradyum
#
# Licensed under the Apache License, Version 2.0 (the "License");
# you may not use this file except in compliance with the License.
# You may obtain a copy of the License at
#
#     http://www.apache.org/licenses/LICENSE-2.0
#
# Unless required by applicable law or agreed to in writing, software
# distributed under the License is distributed on an "AS IS" BASIS,
# WITHOUT WARRANTIES OR CONDITIONS OF ANY KIND, either express or implied.
# See the License for the specific language governing permissions and
# limitations under the License.

from ament_index_python.packages import get_package_share_directory
from launch import LaunchDescription
from launch.actions import ExecuteProcess
from launch_ros.actions import ComposableNodeContainer, Node
from launch_ros.descriptions import ComposableNode

def generate_launch_description():

    ld = LaunchDescription()

    dual_laser_merger_node = ComposableNodeContainer(
        name='demo_container',
        namespace='',
        package='rclcpp_components',
        executable='component_container',
        composable_node_descriptions=[
            ComposableNode(
                package='dual_laser_merger',
                plugin='merger_node::MergerNode',
                name='dual_laser_merger',
                parameters=[
                    {'laser_1_topic': '/lidar1/scan'},
                    {'laser_2_topic': '/lidar2/scan'},
                    {'merged_scan_topic': '/scan'},
                    {'target_frame': 'laser_frame'},
                    {'laser_1_x_offset': 0.0},
                    {'laser_1_y_offset': 0.0},
                    {'laser_1_yaw_offset': 0.0},
                    {'laser_2_x_offset': 0.0},
                    {'laser_2_y_offset': 0.0},
                    {'laser_2_yaw_offset': 0.0},
                    # Raw lidar TF can lag scan stamps by ~0.1s on the real Jetson.
                    {'tolerance': 0.05},
                    {'queue_size': 5},
                    {'angle_increment': 0.001},
                    {'scan_time': 0.067},
                    # Filter out robot body / shell / merge artifacts that appear as 1-5 cm points.
                    {'range_min': 0.05},
                    {'range_max': 25.0},
                    {'min_height': -1.0},
                    {'max_height': 1.0},
                    {'angle_min': -3.141592654},
                    {'angle_max': 3.141592654},
                    {'inf_epsilon': 1.0},
                    {'use_inf': True},
                    {'allowed_radius': 0.45},
                    {'enable_shadow_filter': False},
                    {'enable_average_filter': False},
                    ],
            )
        ],
        output='screen',
    )

    ld.add_action(dual_laser_merger_node)

    rviz_node = Node(
        package='rviz2',
        executable='rviz2',
        output='both',
        arguments=[
            '-d',
            f"{get_package_share_directory('dual_laser_merger')}/config/rviz_config.rviz",
        ],
    )

    ld.add_action(rviz_node)

    return ld
```

### Add a file under launch/ called laser_merger.launch.py:

```sh
vi launch/laser_merger.launch.py
```

#### Paste below content

# real robot merge lidar launch file without rviz2
```py
# Copyright 2024 pradyum
#
# Licensed under the Apache License, Version 2.0 (the "License");
# you may not use this file except in compliance with the License.
# You may obtain a copy of the License at
#
#     http://www.apache.org/licenses/LICENSE-2.0
#
# Unless required by applicable law or agreed to in writing, software
# distributed under the License is distributed on an "AS IS" BASIS,
# WITHOUT WARRANTIES OR CONDITIONS OF ANY KIND, either express or implied.
# See the License for the specific language governing permissions and
# limitations under the License.

from ament_index_python.packages import get_package_share_directory
from launch import LaunchDescription
from launch.actions import ExecuteProcess
from launch_ros.actions import ComposableNodeContainer, Node
from launch_ros.descriptions import ComposableNode

def generate_launch_description():

    ld = LaunchDescription()

    dual_laser_merger_node = ComposableNodeContainer(
        name='demo_container',
        namespace='',
        package='rclcpp_components',
        executable='component_container',
        composable_node_descriptions=[
            ComposableNode(
                package='dual_laser_merger',
                plugin='merger_node::MergerNode',
                name='dual_laser_merger',
                parameters=[
                    {'laser_1_topic': '/lidar1/scan'},
                    {'laser_2_topic': '/lidar2/scan'},
                    {'merged_scan_topic': '/scan'},
                    {'target_frame': 'laser_frame'},
                    {'laser_1_x_offset': 0.0},
                    {'laser_1_y_offset': 0.0},
                    {'laser_1_yaw_offset': 0.0},
                    {'laser_2_x_offset': 0.0},
                    {'laser_2_y_offset': 0.0},
                    {'laser_2_yaw_offset': 0.0},
                    # Raw lidar TF can lag scan stamps by ~0.1s on the real Jetson.
                    {'tolerance': 0.05},
                    {'queue_size': 5},
                    {'angle_increment': 0.001},
                    {'scan_time': 0.067},
                    # Filter out robot body / shell / merge artifacts that appear as 1-5 cm points.
                    {'range_min': 0.05},
                    {'range_max': 25.0},
                    {'min_height': -1.0},
                    {'max_height': 1.0},
                    {'angle_min': -3.141592654},
                    {'angle_max': 3.141592654},
                    {'inf_epsilon': 1.0},
                    {'use_inf': True},
                    {'allowed_radius': 0.45},
                    {'enable_shadow_filter': False},
                    {'enable_average_filter': False},
                    ],
            )
        ],
        output='screen',
    )

    ld.add_action(dual_laser_merger_node)

    return ld
```

### Add a file under launch/ called sim_laser_merger.launch.py:

```sh
vi launch/sim_laser_merger.launch.py
```

# sim merge lidar launch file without rviz
```
from ament_index_python.packages import get_package_share_directory
from launch import LaunchDescription
from launch.actions import DeclareLaunchArgument
from launch.substitutions import LaunchConfiguration
from launch_ros.actions import ComposableNodeContainer, Node
from launch_ros.descriptions import ComposableNode

def generate_launch_description():
    use_sim_time = LaunchConfiguration('use_sim_time', default='false')

    ld = LaunchDescription()
    ld.add_action(DeclareLaunchArgument('use_sim_time', default_value='false'))

    dual_laser_merger_node = ComposableNodeContainer(
        name='demo_container',
        namespace='',
        package='rclcpp_components',
        executable='component_container',
        composable_node_descriptions=[
            ComposableNode(
                package='dual_laser_merger',
                plugin='merger_node::MergerNode',
                name='dual_laser_merger',
                parameters=[
                    {'use_sim_time': use_sim_time},  # Add this line
                    {'laser_1_topic': '/lidar1/scan'},
                    {'laser_2_topic': '/lidar2/scan'},
                    {'merged_scan_topic': '/scan'},
                    {'target_frame': 'laser_frame'},
                    {'laser_1_x_offset': 0.0},
                    {'laser_1_y_offset': 0.0},
                    {'laser_1_yaw_offset': 0.0},
                    {'laser_2_x_offset': 0.0},
                    {'laser_2_y_offset': 0.0},
                    {'laser_2_yaw_offset': 0.0},
                    {'tolerance': 0.05},
                    {'queue_size': 5},
                    {'angle_increment': 0.001},
                    {'scan_time': 0.067},
                    {'range_min': 0.05},
                    {'range_max': 25.0},
                    {'min_height': -1.0},
                    {'max_height': 1.0},
                    {'angle_min': -3.141592654},
                    {'angle_max': 3.141592654},
                    {'inf_epsilon': 1.0},
                    {'use_inf': True},
                    {'allowed_radius': 0.45},
                    {'enable_shadow_filter': False},
                    {'enable_average_filter': False},
                ],
            )
        ],
        output='screen',
    )
    ld.add_action(dual_laser_merger_node)

    return ld
```

### Add a file under launch/ called sim_laser_merger_plus_rviz2.launch.py:

```sh
vi launch/sim_laser_merger_plus_rviz2.launch.py
```

# sim merge lidar launch file with rviz
```
from ament_index_python.packages import get_package_share_directory
from launch import LaunchDescription
from launch.actions import DeclareLaunchArgument
from launch.substitutions import LaunchConfiguration
from launch_ros.actions import ComposableNodeContainer, Node
from launch_ros.descriptions import ComposableNode

def generate_launch_description():
    use_sim_time = LaunchConfiguration('use_sim_time', default='false')

    ld = LaunchDescription()
    ld.add_action(DeclareLaunchArgument('use_sim_time', default_value='false'))

    dual_laser_merger_node = ComposableNodeContainer(
        name='demo_container',
        namespace='',
        package='rclcpp_components',
        executable='component_container',
        composable_node_descriptions=[
            ComposableNode(
                package='dual_laser_merger',
                plugin='merger_node::MergerNode',
                name='dual_laser_merger',
                parameters=[
                    {'use_sim_time': use_sim_time},  # Add this line
                    {'laser_1_topic': '/lidar1/scan'},
                    {'laser_2_topic': '/lidar2/scan'},
                    {'merged_scan_topic': '/scan'},
                    {'target_frame': 'laser_frame'},
                    {'laser_1_x_offset': 0.0},
                    {'laser_1_y_offset': 0.0},
                    {'laser_1_yaw_offset': 0.0},
                    {'laser_2_x_offset': 0.0},
                    {'laser_2_y_offset': 0.0},
                    {'laser_2_yaw_offset': 0.0},
                    {'tolerance': 0.05},
                    {'queue_size': 5},
                    {'angle_increment': 0.001},
                    {'scan_time': 0.067},
                    {'range_min': 0.05},
                    {'range_max': 25.0},
                    {'min_height': -1.0},
                    {'max_height': 1.0},
                    {'angle_min': -3.141592654},
                    {'angle_max': 3.141592654},
                    {'inf_epsilon': 1.0},
                    {'use_inf': True},
                    {'allowed_radius': 0.45},
                    {'enable_shadow_filter': False},
                    {'enable_average_filter': False},
                ],
            )
        ],
        output='screen',
    )
    ld.add_action(dual_laser_merger_node)

    rviz_node = Node(
        package='rviz2',
        executable='rviz2',
        output='both',
        parameters=[{'use_sim_time': use_sim_time}],  # Add this line
        arguments=[
            '-d',
            f"{get_package_share_directory('dual_laser_merger')}/config/rviz_config.rviz",
        ],
    )
    ld.add_action(rviz_node)

    return ld
```

### Modify rviz_config:

#### Backup and truncate the original rviz_config.rviz file

```sh
cp -pa ~/laser_merger_ws/src/dual_laser_merger/config/rviz_config.rviz /tmp/rviz_config.rviz

> ~/laser_merger_ws/src/dual_laser_merger/config/rviz_config.rviz
```

```sh
vi ~/laser_merger_ws/src/dual_laser_merger/config/rviz_config.rviz
```

#### Paste below content
```yaml
Panels:
  - Class: rviz_common/Displays
    Help Height: 138
    Name: Displays
    Property Tree Widget:
      Expanded:
        - /Global Options1
        - /Status1
        - /Merged Laser1/Topic1
      Splitter Ratio: 0.5461847186088562
    Tree Height: 615
  - Class: rviz_common/Selection
    Name: Selection
  - Class: rviz_common/Tool Properties
    Expanded:
      - /2D Goal Pose1
      - /Publish Point1
    Name: Tool Properties
    Splitter Ratio: 0.5886790156364441
  - Class: rviz_common/Views
    Expanded:
      - /Current View1
    Name: Views
    Splitter Ratio: 0.5
  - Class: rviz_common/Time
    Experimental: false
    Name: Time
    SyncMode: 0
    SyncSource: Laser 1
Visualization Manager:
  Class: ""
  Displays:
    - Alpha: 0.5
      Cell Size: 1
      Class: rviz_default_plugins/Grid
      Color: 160; 160; 164
      Enabled: true
      Line Style:
        Line Width: 0.029999999329447746
        Value: Lines
      Name: Grid
      Normal Cell Count: 0
      Offset:
        X: 0
        Y: 0
        Z: 0
      Plane: XY
      Plane Cell Count: 10
      Reference Frame: <Fixed Frame>
      Value: true
    - Alpha: 1
      Autocompute Intensity Bounds: true
      Autocompute Value Bounds:
        Max Value: 10
        Min Value: -10
        Value: true
      Axis: Z
      Channel Name: intensity
      Class: rviz_default_plugins/LaserScan
      Color: 248; 228; 92
      Color Transformer: FlatColor
      Decay Time: 0
      Enabled: true
      Invert Rainbow: false
      Max Color: 255; 255; 255
      Max Intensity: 4898
      Min Color: 0; 0; 0
      Min Intensity: 300
      Name: Laser 1
      Position Transformer: XYZ
      Selectable: true
      Size (Pixels): 3
      Size (m): 0.03
      Style: Flat Squares
      Topic:
        Depth: 5
        Durability Policy: Volatile
        Filter size: 10
        History Policy: Keep Last
        Reliability Policy: Reliable
        Value: /lidar1/scan
      Use Fixed Frame: true
      Use rainbow: true
      Value: true
    - Alpha: 1
      Autocompute Intensity Bounds: true
      Autocompute Value Bounds:
        Max Value: 10
        Min Value: -10
        Value: true
      Axis: Z
      Channel Name: intensity
      Class: rviz_default_plugins/LaserScan
      Color: 87; 227; 137
      Color Transformer: FlatColor
      Decay Time: 0
      Enabled: true
      Invert Rainbow: false
      Max Color: 255; 255; 255
      Max Intensity: 64653
      Min Color: 0; 0; 0
      Min Intensity: 457
      Name: Laser 2
      Position Transformer: XYZ
      Selectable: true
      Size (Pixels): 3
      Size (m): 0.03
      Style: Flat Squares
      Topic:
        Depth: 5
        Durability Policy: Volatile
        Filter size: 10
        History Policy: Keep Last
        Reliability Policy: Reliable
        Value: /lidar2/scan
      Use Fixed Frame: true
      Use rainbow: true
      Value: true
    - Alpha: 1
      Autocompute Intensity Bounds: true
      Autocompute Value Bounds:
        Max Value: 10
        Min Value: -10
        Value: true
      Axis: Z
      Channel Name: intensity
      Class: rviz_default_plugins/LaserScan
      Color: 255; 255; 255
      Color Transformer: FlatColor
      Decay Time: 0
      Enabled: true
      Invert Rainbow: false
      Max Color: 255; 255; 255
      Max Intensity: 4096
      Min Color: 0; 0; 0
      Min Intensity: 0
      Name: Merged Laser
      Position Transformer: XYZ
      Selectable: true
      Size (Pixels): 3
      Size (m): 0.03
      Style: Flat Squares
      Topic:
        Depth: 5
        Durability Policy: Volatile
        Filter size: 10
        History Policy: Keep Last
        Reliability Policy: Best Effort
        Value: /scan
      Use Fixed Frame: true
      Use rainbow: true
      Value: true
    - Class: rviz_default_plugins/TF
      Enabled: true
      Filter (blacklist): ""
      Filter (whitelist): ""
      Frame Timeout: 15
      Frames:
        All Enabled: true
        lidar1_laser:
          Value: true
        lidar2_laser:
          Value: true
        base_link:
          Value: true
      Marker Scale: 1
      Name: TF
      Show Arrows: true
      Show Axes: true
      Show Names: true
      Tree:
        base_link:
          lidar1_laser:
            {}
          lidar2_laser:
            {}
      Update Interval: 0
      Value: true
  Enabled: true
  Global Options:
    Background Color: 48; 48; 48
    Fixed Frame: base_link
    Frame Rate: 30
  Name: root
  Tools:
    - Class: rviz_default_plugins/Interact
      Hide Inactive Objects: true
    - Class: rviz_default_plugins/MoveCamera
    - Class: rviz_default_plugins/Select
    - Class: rviz_default_plugins/FocusCamera
    - Class: rviz_default_plugins/Measure
      Line color: 128; 128; 0
    - Class: rviz_default_plugins/SetInitialPose
      Covariance x: 0.25
      Covariance y: 0.25
      Covariance yaw: 0.06853891909122467
      Topic:
        Depth: 5
        Durability Policy: Volatile
        History Policy: Keep Last
        Reliability Policy: Reliable
        Value: /initialpose
    - Class: rviz_default_plugins/SetGoal
      Topic:
        Depth: 5
        Durability Policy: Volatile
        History Policy: Keep Last
        Reliability Policy: Reliable
        Value: /goal_pose
    - Class: rviz_default_plugins/PublishPoint
      Single click: true
      Topic:
        Depth: 5
        Durability Policy: Volatile
        History Policy: Keep Last
        Reliability Policy: Reliable
        Value: /clicked_point
  Transformation:
    Current:
      Class: rviz_default_plugins/TF
  Value: true
  Views:
    Current:
      Class: rviz_default_plugins/Orbit
      Distance: 8.595158576965332
      Enable Stereo Rendering:
        Stereo Eye Separation: 0.05999999865889549
        Stereo Focal Distance: 1
        Swap Stereo Eyes: false
        Value: false
      Focal Point:
        X: 0
        Y: 0
        Z: 0
      Focal Shape Fixed Size: true
      Focal Shape Size: 0.05000000074505806
      Invert Z Axis: false
      Name: Current View
      Near Clip Distance: 0.009999999776482582
      Pitch: 0.8947969675064087
      Target Frame: <Fixed Frame>
      Value: Orbit (rviz)
      Yaw: 3.060399055480957
    Saved: ~
Window Geometry:
  Displays:
    collapsed: false
  Height: 1011
  Hide Left Dock: false
  Hide Right Dock: false
  QMainWindow State: 000000ff00000000fd0000000400000000000001f400000331fc0200000008fb0000001200530065006c0065006300740069006f006e00000001e10000009b0000005d00fffffffb0000001e0054006f006f006c002000500072006f007000650072007400690065007302000001ed000001df00000185000000a3fb000000120056006900650077007300200054006f006f02000001df000002110000018500000122fb000000200054006f006f006c002000500072006f0070006500720074006900650073003203000002880000011d000002210000017afb000000100044006900730070006c006100790073010000003f00000331000000cc00fffffffb0000002000730065006c0065006300740069006f006e00200062007500660066006500720200000138000000aa0000023a00000294fb00000014005700690064006500530074006500720065006f02000000e6000000d2000003ee0000030bfb0000000c004b0069006e0065006300740200000186000001060000030c00000261000000010000015d00000331fc0200000003fb0000001e0054006f006f006c002000500072006f00700065007200740069006500730100000041000000780000000000000000fb0000000a00560069006500770073010000003f00000331000000a900fffffffb0000001200530065006c0065006300740069006f006e010000025a000000b200000000000000000000000200000490000000a9fc0100000001fb0000000a00560069006500770073030000004e00000080000002e100000197000000030000073e0000005efc0100000002fb0000000800540069006d006501000000000000073e0000026f00fffffffb0000000800540069006d00650100000000000004500000000000000000000003e10000033100000004000000040000000800000008fc0000000100000002000000010000000a0054006f006f006c00730100000000ffffffff0000000000000000
  Selection:
    collapsed: false
  Time:
    collapsed: false
  Tool Properties:
    collapsed: false
  Views:
    collapsed: false
  Width: 1854
  X: 66
  Y: 32
```

## Build:
```sh
cd ~/laser_merger_ws
source /opt/ros/humble/setup.bash
colcon build --symlink-install
```

## Run Real Robot Merged Lidar with rviz2
```sh
cd ~/laser_merger_ws
source /opt/ros/humble/setup.bash
source install/setup.bash
ros2 launch dual_laser_merger laser_merger_plus_rviz2.launch.py
```

## Run Real Robot Merged Lidar without rviz2
```sh
cd ~/laser_merger_ws
source /opt/ros/humble/setup.bash
source install/setup.bash
ros2 launch dual_laser_merger laser_merger.launch.py
```

## Run Sim Robt Merged Lidar without rviz2
```sh
cd ~/laser_merger_ws
source /opt/ros/humble/setup.bash
source install/setup.bash
ros2 launch dual_laser_merger sim_laser_merger.launch.py
```

## Run Sim Robt Merged Lidar with rviz2
```sh
cd ~/laser_merger_ws
source /opt/ros/humble/setup.bash
source install/setup.bash
ros2 launch dual_laser_merger sim_laser_merger_plus_rviz2.launch.py
```

Lidar Merged Launch Default View

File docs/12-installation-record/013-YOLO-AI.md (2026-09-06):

# Jetson-Inference

### Build from source
[Instructions](https://github.com/dusty-nv/jetson-inference/blob/master/docs/building-repo-2.md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)

```
sudo apt-get update
sudo apt-get install git cmake libpython3-dev python3-numpy
git clone --recursive --depth=1 https://github.com/dusty-nv/jetson-inference
cd jetson-inference
mkdir build
cd build
cmake ../
```

I got an error at the `make` command.

Edit `jetson-inference/utils/python/bindings/CMakeLists.txt` and comment out:
```
if(${NUMPY_FOUND})
        target_link_libraries(jetson-utils-python-${PYTHON_VERSION_MAJOR}${PYTHON_VERSION_MINOR} npymath)
endif()
```

to

```
if(${NUMPY_FOUND})
       # target_link_libraries(jetson-utils-python-${PYTHON_VERSION_MAJOR}${PYTHON_VERSION_MINOR} npymath)
endif()
```

Then, continue:

```
make
sudo make install
sudo ldconfig
```

I got a couple errors, so I decided to try to install YOLO.

<hr>

# YOLO using ROS2

[Instructions](https://github.com/mgonzs13/yolo_ros?tab=readme-ov-file#usage)
```
mkdir -p ~/ros2_ws/src
cd ~/ros2_ws/src
git clone https://github.com/mgonzs13/yolo_ros.git
pip3 install -r yolo_ros/requirements.txt
cd ~/ros2_ws
rosdep install --from-paths src --ignore-src -r -y
colcon build
```

# Clone this repo
```
mkdir -p ~/yolo_ws/src
cd ~/yolo_ws/src
git clone https://github.com/mgonzs13/yolo_ros.git
```

# Install uv and python dependencies
```
curl -LsSf https://astral.sh/uv/install.sh | sh
source ~/.bashrc
cd ~/yolo_ws/src/yolo_ros
uv sync
```

# Install rosdep dependencies and build
```
cd ~/yolo_ws
rosdep update
rosdep install --from-paths src --ignore-src -r -y
colcon build
source install/setup.bash
```

```
export ROS_DOMAIN_ID=30
export XRCE_DOMAIN_ID_OVERRIDE=30
ros2 launch yolo_bringup yolo.launch.py \
  model:=$HOME/wro_ign_gazebo_sim/install/hiway_perception/share/hiway_perception/model/wro_obstacle_detector.pt \
  input_image_topic:=/camera/camera/color/image_raw \
  input_depth_topic:=/camera/camera/aligned_depth_to_color/image_raw \
  input_depth_info_topic:=/camera/camera/color/camera_info \
  use_3d:=True \
  target_frame:=camera_color_optical_frame \
  device:=cpu
```

```
ros2 topic echo /yolo/detections_3d
```

#No need
Then,

```
docker build -t yolo_ros .
docker run -it --rm --gpus all yolo_ros
```

Inside docker we can run:

```
export ROS_DOMAIN_ID=30
export XRCE_DOMAIN_ID_OVERRIDE=30
ros2 launch yolo_bringup yolov5.launch.py input_image_topic:=/camera/camera/color/image_raw
```

We will get an error that an invalid CUDA device was requested. Install the [NVIDIA container toolkit](#nvidia-container-toolkit), then proceed.

I can't seem to get GPU acceleration working for now, so use:

```
export ROS_DOMAIN_ID=30
export XRCE_DOMAIN_ID_OVERRIDE=30
ros2 launch yolo_bringup yolov5.launch.py input_image_topic:=/camera/camera/color/image_raw device:=cpu
```

<hr>

# NVIDIA Container Toolkit
[Reference](https://docs.nvidia.com/datacenter/cloud-native/container-toolkit/latest/install-guide.html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)

```
sudo apt-get update && sudo apt-get install -y --no-install-recommends \
   curl \
   gnupg2

curl -fsSL https://nvidia.github.io/libnvidia-container/gpgkey | sudo gpg --dearmor -o /usr/share/keyrings/nvidia-container-toolkit-keyring.gpg \
  && curl -s -L https://nvidia.github.io/libnvidia-container/stable/deb/nvidia-container-toolkit.list | \
    sed 's#deb https://#deb [signed-by=/usr/share/keyrings/nvidia-container-toolkit-keyring.gpg] https://#g' | \
    sudo tee /etc/apt/sources.list.d/nvidia-container-toolkit.list

sudo apt-get update

export NVIDIA_CONTAINER_TOOLKIT_VERSION=1.18.1-1
  sudo apt-get install -y \
      nvidia-container-toolkit=${NVIDIA_CONTAINER_TOOLKIT_VERSION} \
      nvidia-container-toolkit-base=${NVIDIA_CONTAINER_TOOLKIT_VERSION} \
      libnvidia-container-tools=${NVIDIA_CONTAINER_TOOLKIT_VERSION} \
      libnvidia-container1=${NVIDIA_CONTAINER_TOOLKIT_VERSION}
```

Then, configure Docker:

```
sudo nvidia-ctk runtime configure --runtime=docker

sudo systemctl restart docker
```

<hr>

# YOLO with RealSense Camera

In an outside terminal:
```
export ROS_DOMAIN_ID=30
export XRCE_DOMAIN_ID_OVERRIDE=30
ros2 launch realsense2_camera rs_launch.py align_depth.enable:=True
```

In another terminal:
```
docker run -it --rm --gpus all yolo_ros
```

In Docker:
```
export ROS_DOMAIN_ID=30
export XRCE_DOMAIN_ID_OVERRIDE=30
ros2 launch yolo_bringup yolo.launch.py input_image_topic:=/camera/camera/color/image_raw input_depth_topic:=/camera/camera/depth/image_rect_raw input_depth_info_topic:=/camera/camera/depth/camera_info device:=cpu use_3d:=True target_frame:=camera_link
```

Open RViz2.

Under **Global Options**, set `Fixed Frame` to `camera_link`.

At the bottom left,

Click **Add**, then click `By Topic` at the top, and click `/camera` -> `/camera` -> `/aligned_depth_to_color` -> `/image_raw` -> `DepthCloud`.

Click **Ok**.

Now, in the left panel, **Displays**, you will see a new item, **DepthCloud**.

Expand **DepthCloud**, and set **Depth Map Topic** to `/camera/camera/aligned_depth_to_color/image_raw`.

Set **Color Image Topic** to `/camera/camera/color/image_raw`.

At the right panel, **Views**, change **Type** to `FrameAligned`.

Change **Point towards** to `+x axis`, then click `Zero` next to **Type**.

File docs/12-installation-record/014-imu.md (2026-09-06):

# TM171 IMU: Installation, Configuration, and Verification

This record describes the ROS 2 setup used for the SYD Dynamics TransducerM TM171 IMU. It is the detailed companion to the [Chapter 12 operating guide](../12-build-and-operation-guide.md#system-installation-and-initialisation). Use detected device paths and team deployment values; do not copy a personal user name, host name, or absolute home-directory path into the configuration.

## 1. Obtain the ROS 2 Driver Source

Download the ROS 2 example package from the [SYD Dynamics TransducerM ROS 2 download page](https://www.syd-dynamics.com/download/transducerm_example_ros2-pkg/). The downloaded archive is named `TransducerM_Example_ROS2-pkg.zip`.

Create a separate ROS 2 workspace and place the package in its `src` directory:

```bash
mkdir -p "$HOME/imu_ws/src"
cd "$HOME/Downloads"
unzip TransducerM_Example_ROS2-pkg.zip
mv "$HOME/Downloads/TransducerM_Example_ROS2-pkg/TransducerM_Example_ROS2-pkg_V1-1" \
  "$HOME/imu_ws/src/tm_imu"
ls "$HOME/imu_ws/src"
```

The last command should list `tm_imu`.

### Project-maintained driver change

The driver was adjusted so that the published transform reads its parent frame from the `parent_frame_id` parameter rather than using a hard-coded `world` frame. The maintained source is held in the team repository:

```bash
git clone git@github.com:<team-github-account>/tm_imu.git "$HOME/imu_ws/src/tm_imu"
```

In `src/tm_imu_node.cpp`, the relevant `TMSerial::PublishTransform()` implementation assigns the configurable parent frame:

```cpp
void TMSerial::PublishTransform()
{
    geometry_msgs::msg::TransformStamped transform_;
    transform_.header.stamp = this->get_clock()->now();
    transform_.header.frame_id = this->get_parameter("parent_frame_id").as_string();
    transform_.child_frame_id = this->get_parameter("imu_frame_id").as_string();
    transform_.transform.translation.x = this->get_parameter("transform").as_double_array()[0];
    transform_.transform.translation.y = this->get_parameter("transform").as_double_array()[1];
    transform_.transform.translation.z = this->get_parameter("transform").as_double_array()[2];
    transform_.transform.rotation.x = imu_data_msg.orientation.x;
    transform_.transform.rotation.y = imu_data_msg.orientation.y;
    transform_.transform.rotation.z = imu_data_msg.orientation.z;
    transform_.transform.rotation.w = imu_data_msg.orientation.w;
    tf_broadcaster_->sendTransform(transform_);
}
```

## 2. Identify the IMU Serial Device

The TM171 enumerates as an STM32 USB Virtual COM device. The rear LiDAR's CP2102 serial converter is a different device and must not be assigned to `imu_port`.

Run the following after connecting both devices:

```bash
lsusb
ls /dev/ttyUSB*
ls /dev/ttyACM*
ls -l /dev/serial/by-id
dmesg | grep -E 'tty(USB|ACM)'
```

The recorded vehicle setup identified the devices as follows:

| Device | USB identification | Linux device | Purpose |
|---|---|---|---|
| TM171 IMU | STM32 Virtual COM | `/dev/ttyACM0` | IMU serial data |
| CP2102 converter | Silicon Labs `10c4:ea60` | `/dev/ttyUSB0` | Rear LiDAR UART-to-USB bridge |
| RealSense D435f | Intel USB camera | video device | Depth camera |

Typical supporting log lines are:

```text
cdc_acm ... ttyACM0: USB ACM device
cp210x converter now attached to ttyUSB0
```

On another vehicle or after reconnecting hardware, use the currently detected path instead of assuming these names remain unchanged.

## 3. Configure the Driver

Edit `config/params.yaml` in the driver source:

```bash
vi "$HOME/imu_ws/src/tm_imu/config/params.yaml"
```

The package default used `/dev/ttyUSB0`, a `base_link` parent frame, and a `5 ms` timer. The installed configuration uses the IMU device, the vehicle IMU frame, and a less frequent update period:

```yaml
tm_imu:
  ros__parameters:
    imu_baudrate: 115200
    imu_port: "/dev/ttyACM0"
    imu_frame_id: "imu"
    parent_frame_id: "imu_link"
    timer_period: 30
    transform: [0.0, 0.0, 0.0, 0.0, 0.0, 0.0]
```

`timer_period: 30` replaces the original `5 ms` configuration because the faster period was unnecessary. The IMU-to-vehicle translation is maintained in the robot's URDF/Xacro coordinate model; an earlier unused local configuration contained `transform: [-0.008, 0.0, 0.0710, 0.0, 0.0, 0.0]`.

## 4. Build and Launch

Build from the workspace root, not from `src`:

```bash
cd "$HOME/imu_ws"
source /opt/ros/humble/setup.bash
colcon build
source install/setup.bash
ros2 launch tm_imu imu.launch.py
```

The recorded build completed successfully in about 20 seconds. The upstream `serialib.cpp` emitted warnings that `charRead < 0` was always false because of the type range; these warnings did not prevent the `tm_imu` package from building.

## 5. Verify ROS 2 Topics and Transform

Open a new terminal and load the same workspace:

```bash
cd "$HOME/imu_ws"
source /opt/ros/humble/setup.bash
source install/setup.bash
ros2 topic list
```

Expected IMU interfaces are:

```text
/imu_data
/imu_data_mag
/imu_data_rpy
/tf
```

Inspect each data stream individually:

```bash
ros2 topic echo /imu_data
ros2 topic echo /imu_data_rpy
ros2 topic echo /imu_data_mag
```

The `/imu_data` message carries the orientation and inertial measurements. `/imu_data_rpy` and `/imu_data_mag` provide the driver's roll-pitch-yaw and magnetic-field outputs. Confirm that message timestamps advance and that the frame identifier agrees with the configured IMU frame.

## 6. Inspect the Frame in RViz2

Start RViz2:

```bash
ros2 run rviz2 rviz2
```

Add a **TF** display and set the Fixed Frame to the project's selected global frame (for example, `world` when it is published by the rest of the system). Verify that the IMU frame appears below `imu_link` and that its orientation changes when the physical sensor is moved.

## 7. Vehicle-specific Installation Note

The installed TM171 is physically rotated by `180°` so that its cable remains inside the vehicle instead of trailing from the rear. This orientation was checked during driving: the vehicle's automatic steering response was correct, so no separate signal inversion was added. Its complete physical location and the shared sensor coordinate-system method are documented in [Chapter 5](../05-power-and-sensor-architecture.md#sensor-calibration-and-extrinsic-frame-construction).

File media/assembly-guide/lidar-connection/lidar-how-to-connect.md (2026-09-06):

# LiDAR Hardware Connection and Setup Guide

This document describes the hardware wiring and basic setup for using **two LDROBOT STL-27L LiDARs** (front and rear) with a **Jetson Orin Nano** platform.

---

## LiDAR Model

- **Model**: LDROBOT STL-27L

---

## LiDAR Interface

The LDROBOT D500 LiDAR uses a **ZHR-4 1.5mm** connector.

LiDAR interface

---

## Front LiDAR Connection (Direct GPIO to Jetson)

For the **front LiDAR**, we connect it directly to the **Jetson GPIO 40-pin header** using Dupont wires.
Based on experience, GPIO serial communication is more stable than USB-TTL for continuous LiDAR data streaming.

### Front LiDAR Wiring Photos

The white connector on the cable is inserted into the LiDAR ZHR-4 1.5mm port, with the **four small pin holes facing upward**.

Front LiDAR distant photo

Front Lidar Close-up Photos

---

### Front LiDAR ZHR-4 Pin Mapping (Wire Colors)

| LiDAR Signal | Wire Color | Description |
|---|---|---|
| TX | Black | Serial data output |
| PWM | Red | Motor speed control (not used) |
| GND | White | Ground |
| P5V | Yellow | 5V power |

---

### Jetson GPIO Header

- **Carrier Board**: Jetson Orin Nano
- **GPIO Header**: 40-pin

Pin reference documentation:
https://forums.developer.nvidia.com/t/complete-list-of-40-pin-header-options/331516

Jetson Orin Nane 40 Pin

---

### Front LiDAR → Jetson GPIO Mapping

| Jetson GPIO Pin | Function | LiDAR Wire |
|---|---|---|
| Pin 4 | 5.0V | Yellow (P5V) |
| Pin 9 | GND | White (GND) |
| Pin 10 | RX | Black (TX from LiDAR) |
| — | — | Red (PWM) **not connected** |

---

### Connected Front LiDAR to Jetson GPIO

Lidar Connect to Jetson GPIO

---

## Rear LiDAR Connection (USB via TTL Converter)

The **rear LiDAR** uses the same **ZHR-4 1.5mm to Dupont (2.54mm)** cable, but is connected through a **TTL-to-USB A converter (CP2102 module)**.

Although we previously encountered stability issues with USB-TTL converters, this specific setup has been tested and works reliably.

---

### Rear LiDAR Wiring Photo

The white connector is inserted into the LiDAR ZHR-4 1.5mm port with the **four pin holes facing upward**.

Back Lidar 照片

---

### Rear LiDAR ZHR-4 Pin Mapping (Wire Colors)

| LiDAR Signal | Wire Color | Description |
|---|---|---|
| TX | Black | Serial data output |
| PWM | Red | Motor speed control (not used) |
| GND | White | Ground |
| P5V | Yellow | 5V power |

---

### TTL to USB Converter (CP2102) Pin Mapping

TTL Convert To USB Pin

The Dupont wires are connected to the CP2102 module as follows:

| CP2102 Pin | Function | LiDAR Wire |
|---|---|---|
| 3V3 | 3.3V | Not used |
| TX | TX | Not used |
| RX | RX | Black (TX from LiDAR) |
| GND | Ground | White (GND) |
| 5V | 5V Power | Yellow (P5V) |
| — | — | Red (PWM) **not connected** |

---

### Connected Rear LiDAR via USB

The CP2102 USB-A interface is plugged directly into the Jetson USB port.

Lidar Connect to Jetson USB

---

## Software Setup

For software installation, driver configuration, and LiDAR verification, refer to:

https://github.com/clover1983/robot-wro-2026-prepare/blob/main/install-doc/009-LiDAR.md

---

## Notes

- PWM is not used in both front and rear LiDAR setups.
- Both LiDARs operate at **5V power**.
- Serial communication uses **LiDAR TX → Jetson RX** only.
- Front LiDAR uses direct GPIO UART for higher stability.
- The rear LiDAR is connected via USB (CP2102) because the Jetson GPIO header provides only one available RX interface, making it impossible to connect a second LiDAR directly via GPIO.

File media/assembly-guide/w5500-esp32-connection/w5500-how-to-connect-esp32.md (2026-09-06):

# W5500-to-ESP32 wiring guide

The W5500 connects to the ESP32 with Dupont jumper wires. Its RJ45 port connects to Jetson with the selected down-angle-to-straight Ethernet cable.

## W5500 pin reference

w5500 Pin Info

## ESP32 pin reference

esp32 Pin Info

## Wiring map

### Power and control

w5500 3v3 -- esp32 3v3 (same slot line with pin 17, at the picture side left first slot)

w5500 RESET -- esp32 pin 5

w5500 INT -- esp32 pin 7

### SPI and ground

w5500 GND -- esp32 GND (same slot line with pin 17, at the picture side left second slot)

w5500 CLK -- esp32 pin 4

w5500 SI -- esp32 pin 6

w5500 CS -- esp32 pin 44

w5500 SO -- esp32 pin 17

## See below purple line for how to connect

esp32 Pin Info

The W5500 and ESP32 are connected with the Dupont jumper wires shown below.

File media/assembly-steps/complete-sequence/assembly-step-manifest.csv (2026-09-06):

sequence | file | description
1 | assembly-step-001.jpg | All 3D-printed components before installation
2 | assembly-step-002.jpg | Fasteners, standoffs, bearings, and small joining hardware
3 | assembly-step-003.jpg | Power leads prepared for soldering
4 | assembly-step-004.jpg | Completed soldered power harness
5 | assembly-step-005.jpg | Main-power rocker switch
6 | assembly-step-006.jpg | Power harness, rocker switch, and flag terminals connected
7 | assembly-step-007.jpg | 10 cm downward-angle USB-C to straight USB-A male cable for the depth camera
8 | assembly-step-008.jpg | Superseded 30 cm ZH1.5-4P to USB-A male LiDAR cable
9 | assembly-step-009.jpeg | Final 20 cm ZH1.5 to 2.54 mm female-Dupont 1P 4-wire LiDAR harness
10 | assembly-step-010.jpg | 10 cm USB-C to USB-A male cable for the IMU
11 | assembly-step-011.jpg | 30 cm motor cable
12 | assembly-step-012.jpg | 20 cm servo cable
13 | assembly-step-013.jpg | Steering servo
14 | assembly-step-014.jpg | Drive motor
15 | assembly-step-015.jpg | Front and rear LiDAR units
16 | assembly-step-016.jpg | IMU gyroscope
17 | assembly-step-017.jpg | D435f depth camera
18 | assembly-step-018.jpg | ESP32 module and carrier board with OLED installed
19 | assembly-step-019.jpg | Jetson Orin Nano Super Developer Kit
20 | assembly-step-020.jpg | Large-capacity and small-capacity battery options
21 | assembly-step-021.jpg | 3D-printed chassis with silicone front wheels and smooth rear wheels
22 | assembly-step-022.jpeg | Front axle, servo, and Ackermann steering assembly, view 1
23 | assembly-step-023.jpeg | Front axle, servo, and Ackermann steering assembly, view 2
24 | assembly-step-024.jpg | Ackermann front-wheel steering knuckle
25 | assembly-step-025.jpg | Top-front oblique view of the Ackermann front axle
26 | assembly-step-026.jpg | Front view of the Ackermann front axle
27 | assembly-step-027.jpg | Rear view of the assembled Ackermann front axle
28 | assembly-step-028.jpg | Second rear view of the assembled Ackermann front axle
29 | assembly-step-029.jpg | Front view of the assembled Ackermann front axle
30 | assembly-step-030.jpg | Ackermann front axle connected to the servo, showing steering deflection
31 | assembly-step-031.jpg | Rear-axle assembly
32 | assembly-step-032.jpg | Rear-axle pulleys and shared axle
33 | assembly-step-033.jpg | Rear axle with the motor installed
34 | assembly-step-034.jpg | Rear motor and pulley detail, view 1
35 | assembly-step-035.jpg | Rear motor and pulley detail, view 2
36 | assembly-step-036.jpg | Custom 65 mm smooth rear wheels to reduce tyre scrub
37 | assembly-step-037.jpg | Large rear-wheel retaining nut
38 | assembly-step-038.jpg | Rear-wheel bearing
39 | assembly-step-039.jpg | Hollow metal rear-axle tube detail
40 | assembly-step-040.jpg | Top view of the open central chassis cavity before the first cover plate, view 1
41 | assembly-step-041.jpg | Top view of the open central chassis cavity before the first cover plate, view 2
42 | assembly-step-042.jpg | Top view of the rear chassis with battery and retaining plate, view 1
43 | assembly-step-043.jpg | Top view of the rear chassis with battery and retaining plate, view 2
44 | assembly-step-044.jpg | Top view after the second-layer cover plate is installed, view 1
45 | assembly-step-045.jpg | Top view after the second-layer cover plate is installed, view 2
46 | assembly-step-046.jpg | Second-layer front-LiDAR mounting holes
47 | assembly-step-047.jpg | Second-layer dual-LiDAR mounting: screw holes, trays, and offset mounting detail
48 | assembly-step-048.jpg | Second-layer rear-LiDAR mounting holes
49 | assembly-step-049.jpg | Top overview after LiDAR installation
50 | assembly-step-050.jpg | Front overview after LiDAR installation
51 | assembly-step-051.jpg | Rear overview after LiDAR installation
52 | assembly-step-052.jpg | Left-side overview after LiDAR installation
53 | assembly-step-053.jpg | Right-side overview after LiDAR installation
54 | assembly-step-054.jpg | Second-layer split power lead, display lead, and servo lead routed out
55 | assembly-step-055.jpg | In-progress second layer with mounted LiDARs, legacy LiDAR leads, brass standoffs, servo lead, and display cable opening
56 | assembly-step-056.jpg | Third-layer upper plate installed with two LiDAR leads and power lead routed out
57 | assembly-step-057.jpg | Third-layer upper-plate installation detail with two LiDAR leads and power lead
58 | assembly-step-058.jpg | Third-layer upper plate with motor lead routed out and second-layer tray fixed to four brass standoffs
59 | assembly-step-059.jpg | Depth-camera mounting bracket before installation, front view
60 | assembly-step-060.jpg | Depth-camera mounting bracket before installation, rear view
61 | assembly-step-061.jpg | Installing the depth camera and tightening screws
62 | assembly-step-062.jpg | Depth camera installed on the third layer
63 | assembly-step-063.jpg | ESP32 installed on the third layer
64 | assembly-step-064.jpg | ESP32 and speaker installed on the third layer
65 | assembly-step-065.jpeg | IMU cable connection before installation on the third layer
66 | assembly-step-066.jpg | IMU installed on the third layer
67 | assembly-step-067.jpg | Jetson and its two support brackets on the rear half of the third layer
68 | assembly-step-068.jpg | Combined Jetson support bracket on the third layer
69 | assembly-step-069.jpg | Jetson support bracket fixed with screws
70 | assembly-step-070.jpg | Right-side top view of the installed Jetson on the rear half of the third layer
71 | assembly-step-071.jpg | W5500 Ethernet module, tray, and cable ties
72 | assembly-step-072.jpg | Top-front view of the installed Jetson on the rear half of the third layer
73 | assembly-step-073.jpg | W5500 Ethernet module and tray secured
74 | assembly-step-074.jpg | W5500 tray installed on the third layer
75 | assembly-step-075.jpg | Top view after W5500 installation
76 | assembly-step-076.jpg | W5500 Ethernet cable connected to Jetson
77 | assembly-step-077.jpg | Servo lead connected to ESP32 on the third layer, view 1
78 | assembly-step-078.jpg | Servo lead connected to ESP32 on the third layer, view 2
79 | assembly-step-079.jpg | DC motor lead connected to ESP32 on the third layer, view 1
80 | assembly-step-080.jpg | DC motor lead connected to ESP32 on the third layer, view 2
81 | assembly-step-081.jpg | Depth camera connected to Jetson on the third layer
82 | assembly-step-082.jpg | IMU connected to Jetson on the rear half of the third layer
83 | assembly-step-083.jpg | Legacy arrangement with two LiDAR USB plugs connected to Jetson
84 | assembly-step-084.jpeg | CP2102 USB-to-TTL adapter
85 | assembly-step-085.jpeg | Front LiDAR connected to Jetson GPIO
86 | assembly-step-086.jpeg | Final rear-LiDAR TTL-to-USB connection on the second layer
87 | assembly-step-087.jpeg | Front LiDAR ZH1.5-4P connection on the second layer
88 | assembly-step-088.jpeg | ZH1.5-4P LiDAR connector insertion detail
89 | assembly-step-089.jpg | Self-soldered DC5521 power branch connected to ESP32
90 | assembly-step-090.jpg | Self-soldered DC5525 power branch connected to Jetson, view 1
91 | assembly-step-091.jpg | Self-soldered DC5525 power branch connected to Jetson, view 2
92 | assembly-step-092.jpg | DC main-power switch with identification marking
93 | assembly-step-093.jpg | Installed DC power-harness switch
94 | assembly-step-094.jpg | DC power switch and flag-terminal detail, view 1
95 | assembly-step-095.jpg | DC power switch and flag-terminal detail, view 2
96 | assembly-step-096.jpg | Complete vehicle, top view
97 | assembly-step-097.jpg | Complete vehicle, left-side view
98 | assembly-step-098.jpg | Complete vehicle, right-side view
99 | assembly-step-099.jpg | Complete vehicle, underside view
100 | assembly-step-100.jpg | Complete vehicle, front view
101 | assembly-step-101.jpg | Complete vehicle, rear view
102 | assembly-step-102.jpg | Newly printed program-start button and its Dupont leads
103 | assembly-step-103.jpeg | Blue program-start button on the left side
104 | assembly-step-104.jpeg | Blue program-start button detail
105 | assembly-step-105.jpeg | Final vehicle, top view
106 | assembly-step-106.jpeg | Final vehicle, right-side view
107 | assembly-step-107.jpeg | Final vehicle, left-side view
108 | assembly-step-108.jpeg | Final vehicle, rear view

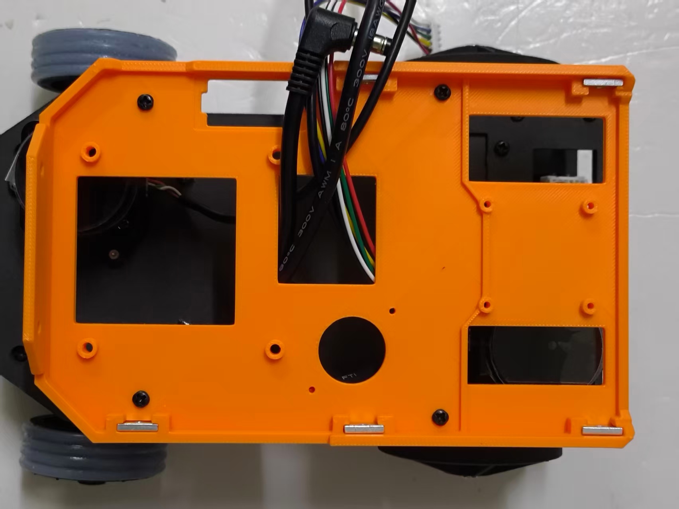
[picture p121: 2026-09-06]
media/assembly-steps/complete-sequence/assembly-step-057.jpg

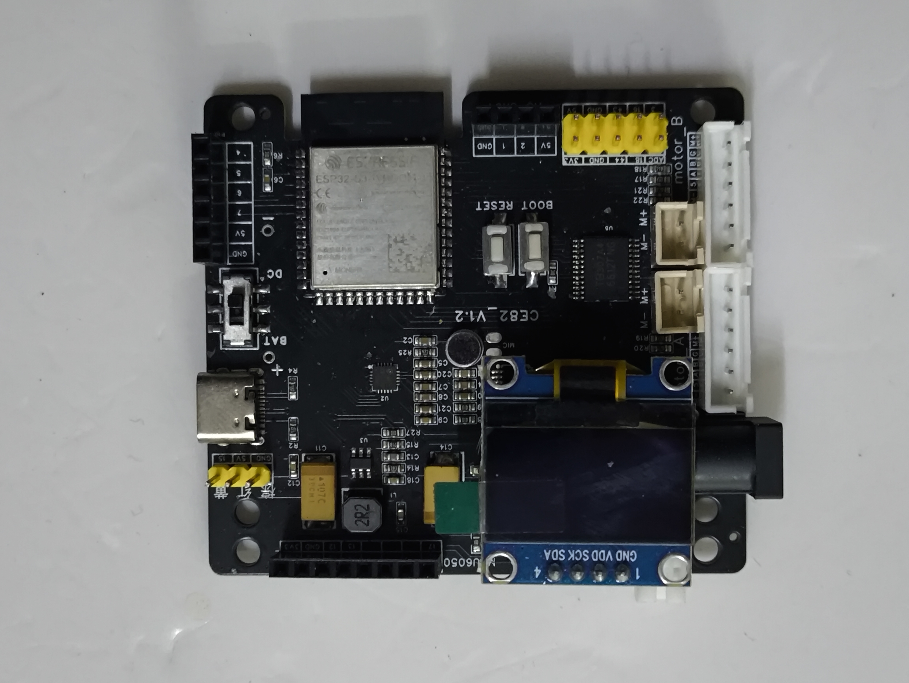
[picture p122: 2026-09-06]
media/assembly-steps/complete-sequence/assembly-step-018.jpg

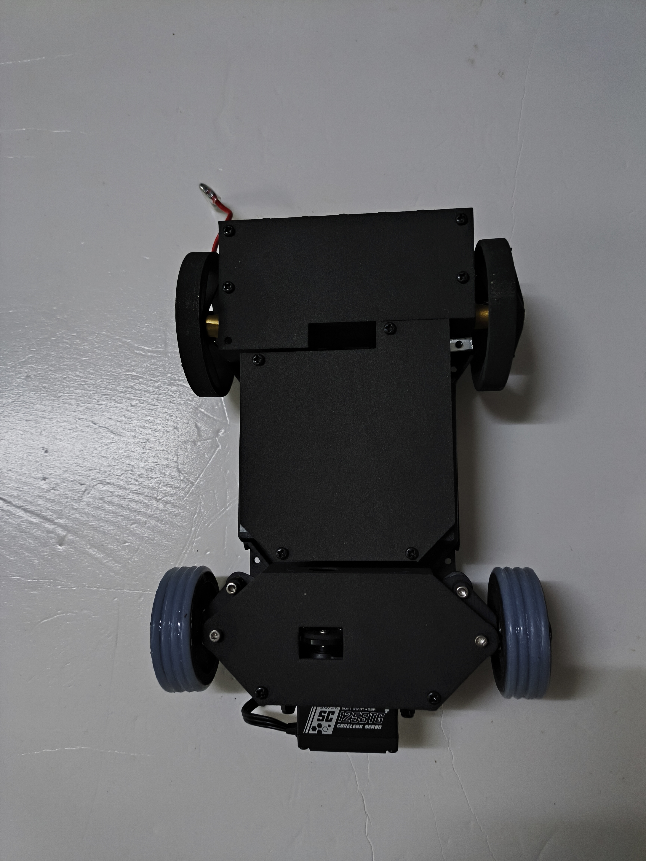
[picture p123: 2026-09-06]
media/assembly-steps/complete-sequence/assembly-step-044.jpg

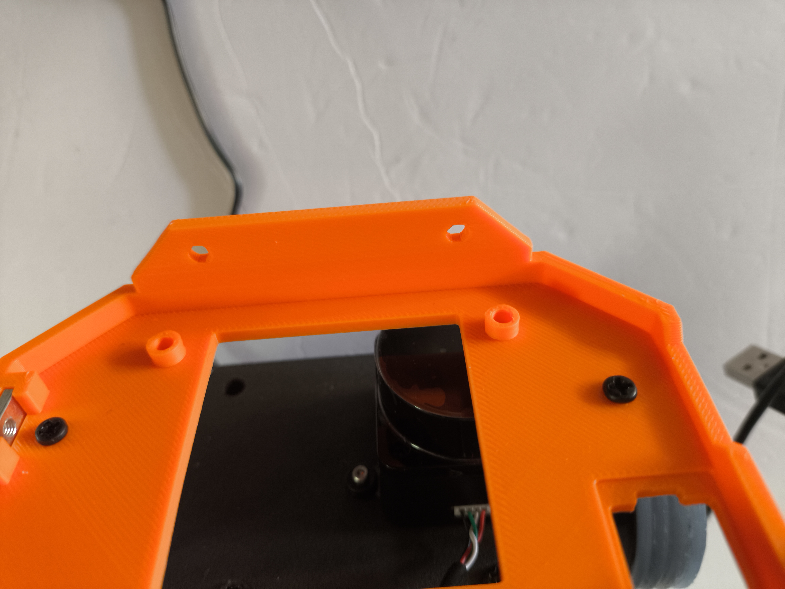
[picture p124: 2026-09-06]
media/assembly-steps/complete-sequence/assembly-step-060.jpg

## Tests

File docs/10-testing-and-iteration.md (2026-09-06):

# Testing and Iteration

## Purpose

Connect the vehicle's mechanical, electrical, sensing, communication, and software iterations to the recorded calculations, observations, and tests. This chapter indexes evidence already documented in Chapters 01–05; it does not present an unmeasured design claim as a physical test result.

## Summary

The current vehicle was reached through linked iterations. Mechanical work changed steering geometry, chassis envelope, rear wheels, support height, and cable routes. Electrical work changed the two-battery concept into one protected 12 V system and removed the 19 V boost module. Sensor work fixed the LiDAR scan planes relative to the `100 mm` course objects, replaced an unresponsive LiDAR cable, and established a common vehicle frame. Communication and control work selected W5500 wired Ethernet and the team's own planning chain after alternatives did not fit the hardware or narrow course.

## Questions addressed

- Can V3 geometry and positive Ackermann fit the intended `375 mm` turn space better than the earlier parallel-steering design?
- Does the GA25-370 rear drive provide sufficient acceleration and speed while a non-differential rear axle remains controllable?
- Can one 12 V battery, direct Jetson input, and the installed harness operate the two-controller vehicle?
- Do the LiDAR positions intersect the `100 mm` course objects and provide usable merged front/rear coverage?
- Which communication, micro-ROS, localization, and planning choices are compatible with the ESP32, Jetson, and narrow course?

## Test and evidence boundaries

The entries distinguish **calculation** (results derived from stated inputs), **vehicle test or observation** (recorded physical outcomes), and **integration verification** (for example, RViz data visibility or successful firmware deployment). Remaining limitations are retained as limitations.

## Tests and results

| Test ID | Question or hypothesis | Setup and metric | Recorded result | Conclusion and next action |
|---|---|---|---|---|
| T-MECH-01 | V3 and positive Ackermann reduce turning demand compared with V1. | Compare V1/V2/V3 dimensions and calculate the V3 rear-axle-centre radius from the `138 mm` wheelbase and `53.7°`/`33.7°` design angles. | V1 required `561–581 mm` in the recorded turn-width calculation. V3 has a `220 mm` body and `138 mm` wheelbase; its theoretical rear-axle-centre radius is about `154.1 mm`. | V3 is the geometric basis. A full swept-envelope test in the `375 mm` space remains the required physical validation. [Mechanical calculation and result](04-mobility-and-mechanical-design.md#tests-and-results) |
| T-MECH-02 | The selected motor and belt reduction meet the low-speed launch target. | Five `0 → 150` straight-line tests on the flat WRO mat with the `4500 mAh` battery; compare measured acceleration/speed with the torque and speed calculation. | Mean `10%–90%` acceleration was `0.545253 m/s²` (sample SD `0.063005 m/s²`); mean stable speed was `0.319176 m/s`. Calculated rear-axle starting torque was about `0.0466 N·m`. | GA25-370 with the `20T:40T` belt reduction covers the selected launch and speed target. [Evidence and calculation](04-mobility-and-mechanical-design.md#tests-and-results) |
| T-MECH-03 | Smoother printed rear wheels reduce shared-axle drag. | Compare large-angle arc driving with early high-friction `68 mm` wheels and final no-silicone `65 mm` printed wheels. | The early wheels caused substantial drag and occasional slip. Arc driving became more stable after the wheel change. | Retain the `65 mm` wheels; a differential-free axle cannot eliminate drag completely. [Wheel iteration](04-mobility-and-mechanical-design.md#4-tyre-drag-trade-off-for-the-shared-rear-axle-without-a-differential) |
| T-SENSE-01 | Two 2D LiDARs detect `100 mm` course objects and improve coverage when merged. | Install both scan planes at approximately `85 mm`, below `95 mm`; inspect independent scans and merged `/scan` in RViz. | The scan planes intersect walls, signs, and parking limits. Merge gives intended front/rear coverage; standoffs and looms leave local blank returns. | Retain the dual-LiDAR layout and treat occlusion as an active limitation. [LiDAR merge](03-system-architecture.md#1-dual-lidar-scan-data-merging) · [geometry](05-power-and-sensor-architecture.md#assessment-of-field-geometry-and-sensor-installation-positions) |
| T-SENSE-02 | Inverting the IMU to retain its cable inside the vehicle does not break steering behaviour. | Rotate TM171 `180°` from the cable-out-the-rear orientation, then observe automatic steering. | No steering-direction error was observed; automatic steering remained correct. | Retain the inverted installation and protected cable path. [IMU iteration](05-power-and-sensor-architecture.md#imu-orientation-and-cable-routing-iteration) |
| T-POWER-01 | One battery can supply both controllers without boost-converter mass. | Component power/current assessment and direct `12 V` Jetson test after reviewing the `12 V → 19 V` candidate. | Operating total is `27.12 W / 2.26 A`; short-duration wire-sizing value is `7.6 A`. The program ran stably in most cases from the direct 12 V supply. | Retain one `12 V / 4.5 Ah` battery, direct Jetson DC5525 input, `14 AWG` main lead, and `18 AWG` branches. [Power assessment](05-power-and-sensor-architecture.md#component-power-and-current-assessment) |
| T-COMM-01 | The selected SBM can run micro-ROS and maintain a wired Jetson connection. | Attempt ESP-IDF-component deployment, then deploy with `micro_ros_arduino`; use W5500 between controllers. | `micro_ros_espidf_component` conflicted with the board's ESP-IDF 5.4 environment. `micro_ros_arduino` successfully ran on the ESP32; W5500 became the supported link. | Retain ESP32-S3 + W5500 + `micro_ros_arduino`; monitor Agent restarts with timeout/watchdog handling. [Deployment decision](05-power-and-sensor-architecture.md#why-esp32-s3-was-selected-as-the-sbm) |
| T-SW-01 | Generic SLAM/navigation and EKF packages can serve the narrow course. | Evaluate `slam_toolbox`, RTAB-Map, Nav2, and `robot_localization` against the sensor inputs and `375 mm` course. | SLAM maps jumped; RTAB-Map was less stable; Nav2 inflation did not fit the corridor; EKF output was too noisy. | Use the team-built map, localization, and planner chain with encoder-pulse odometry. [Software trade-off](03-system-architecture.md#software-architecture-trade-off) |

## Iteration record

| Iteration | Problem or constraint | Change | Evidence and outcome |
|---|---|---|---|
| Steering and chassis: V1 → V3 | Parallel steering required corrections and V1 exceeded the target turn space. | Positive Ackermann and V3 geometry replaced it. Dimension comparison, radius calculation, and planner-version corner behaviour support the decision; physical swept-envelope evidence remains open. |
| Rear wheels | The shared rear axle dragged and slipped with high-friction wheels. | `68 mm` commercial wheels were replaced by smoother `65 mm` printed wheels; arc driving became more stable. |
| LiDAR cable and rear connection | The `30 cm` ZH1.5-4P-to-USB-A cable produced no LiDAR response; rear LiDAR needed a serial path. | Final `20 cm` ZHR-4-to-Dupont harnesses were used, with a `5.5 cm` CP2102 TTL-to-USB adapter at the rear. |
| Battery, voltage, and harness | Two batteries and a boost module increased mass, wiring, and start complexity. | One protected `12 V / 4.5 Ah` battery, direct 12 V, and a hand-soldered `14 AWG` main / `18 AWG` branch harness became final. |
| Jetson/IMU support | The early `30 mm` support left the IMU very hot and lacked an external start-button mount. | Clearance was raised to `40 mm`; the final support adds the program-start button. |
| Controller transport and planning | ESP-IDF deployment conflicted; Wi-Fi/USB candidates did not fit. Generic SLAM/navigation was unstable or unsuitable. | The final solution uses `micro_ros_arduino`, W5500 Ethernet, and team-built mapping, localization, state management, and planner code. |

## Regression and pre-run checks

1. Confirm the main switch disconnects the vehicle and the separate program-start button starts the planner only after power-on.
2. Check OLED battery state; stop/recharge before the `9%` blue-flash warning becomes a run-time issue.
3. Verify polarity, connector seating, and internal cable routing; no cable may enter moving, sensing, or external-obstacle zones.
4. Verify both LiDARs are lit; inspect each independent scan and merged `/scan` in RViz.
5. Verify D435f, IMU, encoder direction, and W5500/micro-ROS data paths before motion.
6. After repeated runs inspect belt tension/alignment, wheels, supports, sensor mounts, cable routes, and the upper PLA electronics layer.

## Evidence links

- [Team process and iteration approach](01-team-and-project.md)
- [Requirements and competition constraints](02-requirements-and-constraints.md)
- [System architecture, data flows, and software trade-offs](03-system-architecture.md)
- [Mechanical calculations, tests, and iterations](04-mobility-and-mechanical-design.md)
- [Power, interfaces, calibration, and sensor iterations](05-power-and-sensor-architecture.md)
- [Component power and current CSV](../hardware/electronics/power-budget.csv)
- [Component mass CSV](../hardware/mechanical/calculations/weight-budget.csv)

## Open items

- Record the full swept-envelope test in the representative `375 mm` course location, including repeated-run success count and minimum clearance.
- Continue recording micro-ROS Agent restarts and the effect of watchdog/timeout handling.
- Add dated photographs or video links for each final pre-run inspection and regression check.

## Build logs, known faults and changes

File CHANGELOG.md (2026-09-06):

# Changelog

All notable robot, documentation, and software changes should be recorded here.

## [Unreleased]
### Added
- Initial WRO 2026 documentation framework.

### Changed
- [Describe change and engineering reason.]

### Fixed
- [Describe defect, root cause, and verification.]

## [0.1.0] - YYYY-MM-DD
- First integrated prototype baseline.

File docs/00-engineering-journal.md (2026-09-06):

# Engineering Journal

Use this page as the judge-facing table of contents for the complete engineering journal. It should explain the team's reasoning and evidence, not only the final robot.

For each major claim, link to the supporting calculation, drawing, source file, photograph, log, or test result. Update the [Rubric Evidence Map](13-rubric-evidence-map.md) as evidence is added.

## Journal chapters

1. [Team and Project](01-team-and-project.md)
2. [Requirements and Constraints](02-requirements-and-constraints.md)
3. [System Architecture](03-system-architecture.md)
4. [Mobility and Mechanical Design](04-mobility-and-mechanical-design.md)
5. [Power and Sensor Architecture](05-power-and-sensor-architecture.md)
6. [Software and Control Architecture](06-software-and-control-architecture.md)
7. [Open Challenge Strategy](07-open-challenge-strategy.md)
8. [Obstacle Challenge Strategy](08-obstacle-challenge-strategy.md)
9. [Parking Strategy](09-parking-strategy.md)
10. [Testing and Iteration](10-testing-and-iteration.md)
11. [Risks and Failure Modes](11-risks-and-failure-modes.md)
12. [Build and Operation Guide](12-build-and-operation-guide.md)
13. [Rubric Evidence Map](13-rubric-evidence-map.md)
14. [AI Use and Authorship](14-ai-use-and-authorship.md)

Export the completed journal to `Engineering-Journal.pdf` only if the competition organizer requires a separate PDF submission.

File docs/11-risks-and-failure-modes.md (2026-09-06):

# Risks and Failure Modes

## Purpose

Record the vehicle's identified mechanical, electrical, sensing, communication, software, and operating risks. Every entry gives a detection method, mitigation already present in the vehicle, and the remaining limitation or verification action.

## Summary

The vehicle does not depend on Wi-Fi, a boost converter, an exposed cable, a camera-only obstacle decision, or an unprotected battery installation. Some risks are reduced by design; others remain inherent to the current package, including shared-rear-axle drag, planar-LiDAR occlusion, a high camera position, and occasional micro-ROS Agent restart. The correct response is inspection and verification before each run, not claiming that those risks have disappeared.

## Risk register

| ID | Risk / failure mode | Detection | Mitigation in the current vehicle | Verification or remaining limitation |
|---|---|---|---|---|
| R-01 | The shared rear axle has no differential, so high steering angles can create tyre drag or slip. | Observe large-angle arc driving and inspect tyre behaviour. | Positive Ackermann and smoother `65 mm` printed rear wheels reduce scrub. | Arc testing became more stable, but drag cannot be eliminated completely without a differential. |
| R-02 | Low `7 mm` clearance can cause occasional ground contact. | Inspect the underside and observe travel on the fixed smooth course. | Keep low centre of mass and LiDAR scan height; selected rear-drive output can continue over occasional contact. | This is a deliberate trade-off; inspect the chassis after runs. |
| R-03 | Belt tension, pulley alignment, or fasteners can change and reduce rear-drive reliability. The previous year's plastic transmission gear between motor and bearing repeatedly wore and failed five times, and replacement parts could no longer be purchased. | Rotate the drivetrain by hand; inspect belt tracking, pulley alignment, and fasteners before power-on. | Motor slots and adjustment screws set tension; the critical motor-to-rear-axle transmission uses metal timing pulleys and a timing belt instead of a plastic gear that cannot be reliably replaced. | Repeat inspection after transport and repeated runs. |
| R-04 | Carbon-fibre-filled material can conduct near electronics, while PLA can bend under sustained load. | Inspect board clearance and layer condition after runs. | PA6-CF is restricted to lower load-bearing layers; the upper electronics layer is PLA. | Slight upper PLA bend has not affected operation; retain post-run inspection. |
| R-05 | A battery, connector, or harness fault can stop the vehicle or damage electronics. | Check OLED percentage, connector seating, polarity, continuity, and branch routing before power-on. | One protected `12 V / 4.5 Ah` battery, screw-secured bay, main switch, `14 AWG` main/`18 AWG` branches, and internal cable routing. OLED flashes blue below `9%`. | Recharge before low-battery operation; inspect the hand-soldered split harness and flag terminals. |
| R-06 | Cable movement can contact obstacles, steering, rear wheels, or timing belt. | Inspect the complete route; move steering and wheels by hand before a run. | Route all power, sensor, Ethernet, motor, and servo leads through printed-layer openings inside the body outline. | The inverted-LiDAR cable and camera USB cable are mandatory startup inspection points. |
| R-07 | LiDAR can fail because of cable/connector disturbance; standoffs and looms can block parts of the horizontal scan planes. | Confirm both LiDARs are lit; inspect each scan and merged `/scan` in RViz. | Final `20 cm` ZHR-4-to-Dupont leads replaced the unresponsive USB-A lead; front/rear scans are merged and state management retains prior observations. | Physical occlusion still produces local blank returns. |
| R-08 | D435f can lose an object at very close range because its mount is above `100 mm` and it is not a fisheye camera. | Observe the camera view when the vehicle is approximately `20 mm` from an object. | Use LiDAR distance together with camera colour recognition. | `15°` and `20°` camera-mount variants were made but not installed because they require new extrinsic calibration. |
| R-09 | IMU cable routing or orientation can create mechanical drag or incorrect motion interpretation. | Inspect cable path and observe automatic steering behaviour after installation. | Mount TM171 inverted by `180°` to keep its cable inside the vehicle; establish its transform in the URDF vehicle frame. | Automatic steering remained correct in the recorded observation. |
| R-10 | Program-start input or micro-ROS communication can behave unexpectedly during a run. | Check that one press starts the planner; observe Agent status and communication timeouts. | `robot_autostart` ignores repeated presses after startup; timeout and watchdog handling reduce Agent-restart frequency. | Button-release handling and occasional Agent restarts remain open limitations. |
| R-11 | Generic SLAM, Nav2, or EKF output can give unstable state information in the narrow course. | Observe map stability, obstacle clearance, and state output while evaluating the packages. | Use team-built map, localization, state management, and planner code; derive wheel odometry from encoder pulses. | The current approach is selected for this vehicle/course; continued course testing is required. |

## Operational safety sequence

1. Inspect the screw-retained battery bay, main switch, flag terminals, and split harness before connecting power.
2. Confirm all cables are internal, seated, and clear of moving and sensing areas.
3. Check OLED battery state; do not begin a run after the low-battery warning.
4. Power the vehicle once with the main switch, then use the external program-start button as the separate permitted program operation.
5. Before motion, verify LiDAR, camera, IMU, encoder, and W5500/micro-ROS data paths.
6. After a run, inspect belt, wheels, printed layers, sensor supports, cable routes, and connectors for movement or damage.

## Evidence links

- [Requirements and rule-derived constraints](02-requirements-and-constraints.md)
- [System risks, limitations, and mitigations](03-system-architecture.md#risks-limitations-and-mitigations)
- [Mechanical risks, tests, and reproduction checks](04-mobility-and-mechanical-design.md#risks-limitations-and-mitigations)
- [Electrical safety, sensor placement, and failure points](05-power-and-sensor-architecture.md#electrical-and-wiring-safety-measures)
- [Testing and iteration index](10-testing-and-iteration.md)

## Open items

- Record repeated full-course runs with dated logs/video and report failures separately from successful runs.
- Complete the program-start button release-state handling.
- Continue monitoring micro-ROS Agent restarts and LiDAR/camera coverage limitations after each hardware change.

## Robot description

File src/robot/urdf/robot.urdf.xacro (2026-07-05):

<?xml version="1.0" ?>
<robot name="robot" xmlns:xacro="http://www.ros.org/wiki/xacro" canonical_link='base_link'>
  <xacro:property name="PI" value="3.1415926835897931"/>
  <xacro:property name="wheel_base" value="0.138" />
  <xacro:property name="wheel_track" value="0.135" />
  <xacro:property name="wheel_radius" value="${rear_tyre_r}" />
  <xacro:property name="car_body_length" value="0.22"/>
  <xacro:property name="car_body_width" value="0.12"/>
  <xacro:property name="car_body_height" value="0.145"/>
  <xacro:property name="car_body_mass" value="1.45"/>
  <xacro:property name="rear_tyre_x" value="0"/>
  <xacro:property name="rear_tyre_y" value="0.075"/>
  <xacro:property name="rear_tyre_r" value="0.0323"/>
  <xacro:property name="rear_tyre_length" value="0.02"/>
  <xacro:property name="rear_tyre_mass" value="0.08"/>

  <xacro:property name="rear_tyre_to_carbody_end" value="0.053" />
  <xacro:property name="front_tyre_x" value="0.1328"/>
  <xacro:property name="front_tyre_y" value="0.081"/>
  <xacro:property name="front_tyre_r" value="0.02515"/>
  <xacro:property name="front_tyre_length" value="0.02"/>
  <xacro:property name="front_tyre_mass" value="0.01"/>
  <xacro:property name="str_angle" value="0.6"/>
  <xacro:property name="str_length" value="0.00629"/>
  <xacro:property name="str_radius" value="0.003"/>
  <xacro:property name="str_mass" value="0.002"/>
  <xacro:property name="camera_x" value="0.163" />
  <xacro:property name="camera_y" value="0.0" />
  <xacro:property name="camera_z" value="0.0778" />
  <xacro:property name="camera_box_x" value="0.09" />
  <xacro:property name="camera_box_y" value="0.0258" />
  <xacro:property name="camera_box_z" value="0.025" />
  <xacro:property name="camera_box_mass" value="0.086" />
  <xacro:property name="lidar_box_x" value="0.0463" />
  <xacro:property name="lidar_box_y" value="0.054" />
  <xacro:property name="lidar_box_z" value="0.0348" />
  <xacro:property name="lidar_box_mass" value="0.035" />
  <xacro:property name="front_lidar_x" value="0.1325" />
  <xacro:property name="front_lidar_y" value="-0.023" />
  <xacro:property name="front_lidar_z" value="0.035" />
  <xacro:property name="rear_lidar_x" value="-0.018" />
  <xacro:property name="rear_lidar_y" value="0.028" />
  <xacro:property name="rear_lidar_z" value="0.04" />
  <xacro:property name="imu_x" value="-0.008" />
  <xacro:property name="imu_y" value="0.0" />
  <xacro:property name="imu_z" value="0.0710" />
  <xacro:property name="imu_box_x" value="0.04" />
  <xacro:property name="imu_box_y" value="0.036" />
  <xacro:property name="imu_box_z" value="0.0126" />
  <xacro:property name="imu_box_mass" value="0.019" />
  <xacro:include filename="colours.xacro" />
  <xacro:include filename="inertial_macros.xacro" />
  <link name="base_link"></link>

  <joint name="base_footprint_joint" type="fixed">
    <parent link="base_link"/>
    <child link="base_footprint"/>
    <origin xyz="0 0 ${-wheel_radius}"/>
  </joint>

  <link name="base_footprint"></link>
  <joint name="car_body_joint" type="fixed">
    <parent link="base_link"/>
    <child link="car_body_link"/>
    <origin xyz="0 0 0" rpy="0 0 0"/>
  </joint>

  <link name="car_body_link">
    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

    <xacro:inertial_box mass="${car_body_mass}" x="${car_body_length}" y="${car_body_width}" z="${car_body_height}">
      <origin xyz="0 0 0" rpy="0 0 0"/>
    </xacro:inertial_box>
  </link>
  <joint name="rear_right_wheel_joint" type="continuous">
    <parent link="base_link"/>
    <child link="rear_right_wheel_link"/>
    <origin xyz="${rear_tyre_x} -${rear_tyre_y} ${rear_tyre_r - rear_tyre_r}" rpy="0 0 0"/>
    <axis xyz="0 1 0"/>
    <dynamics damping="0.1"/>
    <limit effort="20" velocity="30"/>
  </joint>

  <link name="rear_right_wheel_link">
    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

    <xacro:inertial_cylinder mass="${rear_tyre_mass}" radius="${rear_tyre_r}" length="${rear_tyre_length}">
      <origin xyz="0 0 0" rpy="0 0 0"/>
    </xacro:inertial_cylinder>

  </link>
  <joint name="rear_left_wheel_joint" type="continuous">
    <parent link="base_link"/>
    <child link="rear_left_wheel_link"/>
    <origin xyz="${rear_tyre_x} ${rear_tyre_y} ${rear_tyre_r - rear_tyre_r}" rpy="0 0 0"/>
    <axis xyz="0 1 0"/>
    <dynamics damping="0.1"/>
    <limit effort="20" velocity="30"/>
  </joint>

  <link name="rear_left_wheel_link">
    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

    <xacro:inertial_cylinder mass="${rear_tyre_mass}" radius="${rear_tyre_r}" length="${rear_tyre_length}">
      <origin xyz="0 0 0" rpy="0 0 0"/>
    </xacro:inertial_cylinder>
  </link>
  <joint name="front_right_steering_joint" type="revolute">
    <parent link="base_link"/>
    <child link="front_right_steering_link"/>
    <origin xyz="${front_tyre_x} -${front_tyre_y} ${front_tyre_r - rear_tyre_r}" rpy="0 0 0"/>
    <axis xyz="0 0 -1"/>
    <limit lower="${-str_angle}" upper="${str_angle}" effort="20" velocity="30"/>
    <dynamics damping="10.0" friction="0.0"/>
  </joint>

  <link name="front_right_steering_link">
    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

    <xacro:inertial_cylinder mass="${str_mass}" radius="${str_radius}" length="${str_length}">
      <origin xyz="0 0 0" rpy="0 0 0"/>
    </xacro:inertial_cylinder>
  </link>
  <joint name="front_right_wheel_joint" type="continuous">
    <parent link="front_right_steering_link"/>
    <child link="front_right_wheel_link"/>
    <origin xyz="0 0 0" rpy="0 0 0"/>
    <axis xyz="0 1 0"/>
    <dynamics damping="0.1"/>
    <limit effort="20" velocity="30"/>
  </joint>

  <link name="front_right_wheel_link">
    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

    <xacro:inertial_cylinder mass="${front_tyre_mass}" radius="${front_tyre_r}" length="${front_tyre_length}">
      <origin xyz="0 0 0" rpy="0 0 0"/>
    </xacro:inertial_cylinder>
  </link>
  <joint name="front_left_steering_joint" type="revolute">
    <parent link="base_link"/>
    <child link="front_left_steering_link"/>
    <origin xyz="${front_tyre_x} ${front_tyre_y} ${front_tyre_r - rear_tyre_r}" rpy="0 0 0"/>
    <axis xyz="0 0 1"/>
    <limit lower="${-str_angle}" upper="${str_angle}" effort="20" velocity="30"/>
    <dynamics damping="10.0" friction="0.0"/>
  </joint>

  <link name="front_left_steering_link">
    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

    <xacro:inertial_cylinder mass="${str_mass}" radius="${str_radius}" length="${str_length}">
      <origin xyz="0 0 0" rpy="0 0 0"/>
    </xacro:inertial_cylinder>
  </link>
  <joint name="front_left_wheel_joint" type="continuous">
    <parent link="front_left_steering_link"/>
    <child link="front_left_wheel_link"/>
    <origin xyz="0 0 0" rpy="0 0 0"/>
    <axis xyz="0 1 0"/>
    <dynamics damping="0.1"/>
    <limit effort="20" velocity="30"/>
  </joint>

  <link name="front_left_wheel_link">
    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

    <xacro:inertial_cylinder mass="${front_tyre_mass}" radius="${front_tyre_r}" length="${front_tyre_length}">
      <origin xyz="0 0 0" rpy="0 0 0"/>
    </xacro:inertial_cylinder>
  </link>
  <joint name="camera_d435f_joint" type="fixed">
    <parent link="base_link"/>
    <child link="camera_d435f"/>
    <origin xyz="${camera_x} ${camera_y} ${camera_z}" rpy="0 0 0"/>
  </joint>

  <link name="camera_d435f">
    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

    <xacro:inertial_box mass="${camera_box_mass}" x="${camera_box_x}" y="${camera_box_y}" z="${camera_box_z}">
      <origin xyz="0 0 0" rpy="0 0 0"/>
    </xacro:inertial_box>
  </link>

  <joint name="camera_d435f_to_camera_link" type="fixed">
    <parent link="camera_d435f"/>
    <child link="camera_link"/>
    <origin xyz="0 0 0" rpy="0 0 0"/>
  </joint>

  <link name="camera_link"/>
  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
  <joint name="front_lidar_joint" type="fixed">
    <parent link="base_link"/>
    <child link="front_lidar"/>
    <origin xyz="${front_lidar_x} ${front_lidar_y} ${front_lidar_z}" rpy="0 0 0"/>
  </joint>

  <link name="front_lidar">
    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

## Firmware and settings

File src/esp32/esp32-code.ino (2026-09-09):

#if defined(ARDUINO_ARCH_ESP32) && defined(CONFIG_IDF_TARGET_ESP32S3)
#pragma message "Building for ESP32-S3: ensure micro_ros_arduino esp32s3 binary exists"
#endif

#include <micro_ros_arduino.h>
#include <Wire.h>
#include <ETH.h>
#include <esp_task_wdt.h>

#define WDT_TIMEOUT_SEC 15
#define MOTOR_COMMAND_TIMEOUT_MS 400
#ifndef WRO_ROS_DOMAIN_ID
#define WRO_ROS_DOMAIN_ID 255
#endif

#include <rcl/error_handling.h>
#include <rcl/rcl.h>
#include <rclc/executor.h>
#include <rclc/rclc.h>
#include <stdio.h>

#include <std_msgs/msg/int32.h>
#include <std_msgs/msg/int32_multi_array.h>
#include <std_msgs/msg/string.h>

#include <sstream>
#include <string>

rcl_publisher_t publisher;
rcl_subscription_t subscriber_oled;
rcl_subscription_t subscriber_servo;
rclc_executor_t executor;
rclc_support_t support;
rcl_init_options_t support_init_options;
rcl_allocator_t allocator;
rcl_node_t node;

rcl_subscription_t subscriber_motor;
rcl_timer_t timer_motor;
std_msgs__msg__Int32 recv_msg_motor;
static uint8_t agent_ping_fail_count = 0;

rcl_publisher_t encoder_publisher;
std_msgs__msg__Int32 send_msg_encoder;
#define ENCODER_UPDATE_SPEED 50
std_msgs__msg__Int32 recv_msg_servo;

std_msgs__msg__String recv_msg_oled;

std_msgs__msg__String send_msg;

rcl_subscription_t subscriber_audio;
std_msgs__msg__Int32MultiArray recv_msg_audio;

rcl_timer_t timer_adc;

#define STRING_BUFFER_SIZE 100

enum AgentState {
  WAITING_AGENT,
  AGENT_AVAILABLE,
  AGENT_CONNECTED,
  AGENT_DISCONNECTED
} agent_state;

#define EXECUTE_EVERY_N_MS(MS, X)                          \
  do {                                                     \
    static volatile int64_t _t = -1;                       \
    if (_t == -1) { _t = uxr_millis(); }                   \
    if ((int64_t)(uxr_millis() - _t) > (MS)) { X; _t = uxr_millis(); } \
  } while (0)

static char    *buf_send_msg   = nullptr;
static char    *buf_recv_oled  = nullptr;
static int32_t *buf_recv_audio = nullptr;

#define RCINIT(fn)                                                             \
  {                                                                            \
    rcl_ret_t temp_rc = fn;                                                    \
    if ((temp_rc != RCL_RET_OK)) {                                             \
      char buf[80];                                                             \
      snprintf(buf, sizeof(buf), "RCINIT ERR %s:%d code=%d",                  \
               __FUNCTION__, __LINE__, temp_rc);                               \
      log_e("%s", buf);                                                        \
      rcl_reset_error();                                                       \
      return false;                                                            \
    }                                                                          \
  }

#define RCCHECK(fn)                                                                        \
  {                                                                                        \
    rcl_ret_t temp_rc = fn;                                                                \
    if ((temp_rc != RCL_RET_OK)) {                                                         \
      char buf[80];                                                                        \
      snprintf(buf, sizeof(buf), "ERR at %s:%d code=%d", __FUNCTION__, __LINE__, temp_rc); \
      error_loop(buf);                                                                     \
    }                                                                                      \
  }
#define RCSOFTCHECK(fn)                                                                    \
  {                                                                                        \
    rcl_ret_t temp_rc = fn;                                                                \
    if ((temp_rc != RCL_RET_OK)) {                                                         \
      char buf[80];                                                                        \
      snprintf(buf, sizeof(buf), "ERR at %s:%d code=%d", __FUNCTION__, __LINE__, temp_rc); \
      log_e("%s", buf);                                                                    \
    }                                                                                      \
  }

void publish_text(const char *text, bool check = true) {
  size_t len = strlen(text);
  if (len >= send_msg.data.capacity)
    len = send_msg.data.capacity - 1;

  memcpy(send_msg.data.data, text, len);
  send_msg.data.data[len] = '\0';
  send_msg.data.size = len;

  if (check) {
    RCSOFTCHECK(rcl_publish(&publisher, &send_msg, NULL));
  } else {
    rcl_publish(&publisher, &send_msg, NULL);
  }
}

void error_loop(const char *msg = "An error occurred") {
  while (1) {
    log_e("%s", msg);
    delay(100);
  }
}

void oled_subscription_callback(const void *msgin) {
  const std_msgs__msg__String *msg =
      (const std_msgs__msg__String *)msgin;

  std::string input(msg->data.data, msg->data.size);

  std::stringstream ss(input);
  std::string command;

  while (std::getline(ss, command)) {

    while (!command.empty() && command.front() == ' ')
      command.erase(0, 1);
    while (!command.empty() && command.back() == ' ')
      command.pop_back();

    if (command.empty())
      continue;

    if (command == "clear") {
      oled_clear();
      continue;
    }

    if (command == "update") {
      oled_update();
      continue;
    }

    if (command.rfind("print ", 0) == 0) {
      std::stringstream cs(command);

      std::string cmd;
      int x, y;
      std::string text;

      if (!(cs >> cmd >> x >> y)) {
        publish_text("ERR: print needs 2 numbers");
        continue;
      }

      std::getline(cs, text);

      if (!text.empty() && text[0] == ' ')
        text.erase(0, 1);

      oled_print(x, y, text.c_str());
      continue;
    }

    if (command.rfind("clear ", 0) == 0) {
      std::stringstream cs(command);

      std::string cmd;
      int x, y, w, h;

      if (!(cs >> cmd >> x >> y >> w >> h)) {
        publish_text("ERR: clear needs 4 numbers");
        continue;
      }

      oled_clear_area(x, y, w, h);
      continue;
    }

    if (command.rfind("mode ", 0) == 0) {
      std::stringstream cs(command);

      std::string cmd;
      bool inverted;

      if (!(cs >> cmd >> inverted)) {
        publish_text("ERR: mode needs 1 number that is 0 or 1");
        continue;
      }

      oled_mode(inverted);
      continue;
    }

    char buf[100];
    snprintf(buf, sizeof(buf), "OLED: Unknown cmd: %s", command.c_str());
    publish_text(buf);
  }

  publish_text("OLED: Commands processed");
}

void servo_subscription_callback(const void *msgin) {
  const std_msgs__msg__Int32 *msg = (const std_msgs__msg__Int32 *)msgin;

  int32_t value = msg->data;
  int32_t set_value = Ctrl_sg90(value);

  log_i("SERVO: cmd=%ld set_value=%ld", (long)value, (long)set_value);
}

extern int32_t motor_a_check_speed;

void motor_safety_stop() {
  motor_submit_command(0);
}

void motor_timer_callback(rcl_timer_t *timer, int64_t last_call_time) {
  RCLC_UNUSED(last_call_time);
  if (timer != NULL) {
    encoder_check_speed();

    publish_encoder(motor_a_check_speed);
  }
}

void publish_encoder(int32_t data) {
  send_msg_encoder.data = data;
  RCSOFTCHECK(rcl_publish(&encoder_publisher, &send_msg_encoder, NULL));
}

void motor_subscription_callback(const void *msgin) {
  const std_msgs__msg__Int32 *msg = (const std_msgs__msg__Int32 *)msgin;
  motor_submit_command(msg->data);
}

void audio_subscription_callback(const void *msgin) {
  const std_msgs__msg__Int32MultiArray *msg = (const std_msgs__msg__Int32MultiArray *)msgin;

  if (msg != NULL && msg->data.size >= 2) {
    float freq = (float)msg->data.data[0];
    int duration_ms = (int)msg->data.data[1];

    if (freq < 20.0f) freq = 20.0f;
    if (freq > 1000.0f) freq = 1000.0f;

    if (duration_ms < 0) duration_ms = 0;
    if (duration_ms > 3000) duration_ms = 3000;

    startTone(freq, duration_ms);

    char log_buf[100];
    snprintf(log_buf, sizeof(log_buf), "TONE: %.0fHz, %dms\r\n", freq, duration_ms);
    publish_text(log_buf);
  } else if (msg != NULL) {
    publish_text("AUDIO ERROR: Received array too small!\r\n");
  } else {
    publish_text("AUDIO ERROR: Received NULL msg!\r\n");
  }
}

void adc_timer_callback(rcl_timer_t *timer, int64_t last_call_time) {
  RCLC_UNUSED(last_call_time);
  if (timer != NULL) {
    displayBatteryVoltage();
    publish_text("ADC: Updated voltage and battery display");
  }
}

extern void odom_udp_init(const char *jetson_ip);
extern void odom_udp_task_start();

bool create_entities() {
  motor_safety_stop();

  memset(&publisher,         0, sizeof(publisher));
  memset(&encoder_publisher, 0, sizeof(encoder_publisher));
  memset(&subscriber_oled,   0, sizeof(subscriber_oled));
  memset(&subscriber_servo,  0, sizeof(subscriber_servo));
  memset(&subscriber_motor,  0, sizeof(subscriber_motor));
  memset(&subscriber_audio,  0, sizeof(subscriber_audio));
  memset(&timer_motor,       0, sizeof(timer_motor));
  memset(&timer_adc,         0, sizeof(timer_adc));
  memset(&executor,          0, sizeof(executor));
  memset(&node,              0, sizeof(node));
  memset(&support,           0, sizeof(support));
  support_init_options = rcl_get_zero_initialized_init_options();
  allocator = rcl_get_default_allocator();

  RCINIT(rcl_init_options_init(&support_init_options, allocator));
  RCINIT(rcl_init_options_set_domain_id(&support_init_options, WRO_ROS_DOMAIN_ID));
  RCINIT(rclc_support_init_with_options(
      &support,
      0,
      NULL,
      &support_init_options,
      &allocator));

  RCINIT(rclc_node_init_default(&node, "micro_ros_esp32_node", "", &support));

  RCINIT(rclc_publisher_init_best_effort(
      &publisher, &node,
      ROSIDL_GET_MSG_TYPE_SUPPORT(std_msgs, msg, String),
      "/microROS/status"));

  std_msgs__msg__String__init(&send_msg);
  send_msg.data.data     = buf_send_msg;
  send_msg.data.capacity = STRING_BUFFER_SIZE;
  send_msg.data.size     = 0;

  RCINIT(rclc_publisher_init_best_effort(
      &encoder_publisher, &node,
      ROSIDL_GET_MSG_TYPE_SUPPORT(std_msgs, msg, Int32),
      "/microROS/encoder_data"));
  std_msgs__msg__Int32__init(&send_msg_encoder);

  RCINIT(rclc_subscription_init_default(
      &subscriber_oled, &node,
      ROSIDL_GET_MSG_TYPE_SUPPORT(std_msgs, msg, String),
      "/microROS/oled_display"));
  std_msgs__msg__String__init(&recv_msg_oled);
  recv_msg_oled.data.data     = buf_recv_oled;
  recv_msg_oled.data.capacity = 500;
  recv_msg_oled.data.size     = 0;

  RCINIT(rclc_subscription_init_best_effort(
      &subscriber_servo, &node,
      ROSIDL_GET_MSG_TYPE_SUPPORT(std_msgs, msg, Int32),
      "/microROS/servo_control"));
  std_msgs__msg__Int32__init(&recv_msg_servo);

  RCINIT(rclc_subscription_init_best_effort(
      &subscriber_motor, &node,
      ROSIDL_GET_MSG_TYPE_SUPPORT(std_msgs, msg, Int32),
      "/microROS/motor_control"));
  std_msgs__msg__Int32__init(&recv_msg_motor);

  RCINIT(rclc_subscription_init_default(
      &subscriber_audio, &node,
      ROSIDL_GET_MSG_TYPE_SUPPORT(std_msgs, msg, Int32MultiArray),
      "/microROS/audio_play"));
  std_msgs__msg__Int32MultiArray__init(&recv_msg_audio);
  recv_msg_audio.data.data     = buf_recv_audio;
  recv_msg_audio.data.capacity = 2;
  recv_msg_audio.data.size     = 0;

  RCINIT(rclc_timer_init_default(
      &timer_motor, &support,
      RCL_MS_TO_NS(ENCODER_UPDATE_SPEED),
      motor_timer_callback));

  RCINIT(rclc_timer_init_default(
      &timer_adc, &support,
      RCL_MS_TO_NS(5000),
      adc_timer_callback));

  RCINIT(rclc_executor_init(&executor, &support.context, 6, &allocator));

  RCINIT(rclc_executor_add_subscription(&executor, &subscriber_oled,  &recv_msg_oled,  &oled_subscription_callback,  ON_NEW_DATA));
  RCINIT(rclc_executor_add_subscription(&executor, &subscriber_servo, &recv_msg_servo, &servo_subscription_callback, ON_NEW_DATA));
  RCINIT(rclc_executor_add_subscription(&executor, &subscriber_motor, &recv_msg_motor, &motor_subscription_callback, ON_NEW_DATA));
  RCINIT(rclc_executor_add_subscription(&executor, &subscriber_audio, &recv_msg_audio, &audio_subscription_callback, ON_NEW_DATA));
  RCINIT(rclc_executor_add_timer(&executor, &timer_motor));
  RCINIT(rclc_executor_add_timer(&executor, &timer_adc));

  if (RMW_RET_OK != rmw_uros_sync_session(1000)) {
    log_w("Clock sync failed – timestamps will be based on local ESP32 clock");
  } else {
    log_i("Clock synced with agent.");
  }
  agent_ping_fail_count = 0;

  static bool odom_udp_started = false;
  if (!odom_udp_started) {
    odom_udp_init("192.168.10.1");  // Jetson IP
    odom_udp_task_start();
    odom_udp_started = true;
  }

  publish_text("Setup completed.");
  log_i("micro-ROS entities created. Odom reset to origin.");
  return true;
}

void destroy_entities() {
  motor_safety_stop();
  Ctrl_sg90(0);
  rmw_context_t *rmw_context = rcl_context_get_rmw_context(&support.context);
  (void)rmw_uros_set_context_entity_destroy_session_timeout(rmw_context, 0);

  rclc_executor_fini(&executor);

  rcl_publisher_fini(&publisher,         &node);
  rcl_publisher_fini(&encoder_publisher, &node);

  rcl_subscription_fini(&subscriber_oled,  &node);
  rcl_subscription_fini(&subscriber_servo, &node);
  rcl_subscription_fini(&subscriber_motor, &node);
  rcl_subscription_fini(&subscriber_audio, &node);

  rcl_timer_fini(&timer_motor);
  rcl_timer_fini(&timer_adc);

  rcl_node_fini(&node);
  rclc_support_fini(&support);
  rcl_init_options_fini(&support_init_options);

  log_i("micro-ROS entities destroyed.");
}

void setup() {
  Wire.begin(13, 12);  // SDA, SCL

  oled_init();
  sg90_pwm_init();
  motor_init();
  battery_adcInit();
  audio_init();

  ethernet_init("192.168.10.1", "192.168.10.2");
  set_microros_ethernet_udp_transports("192.168.10.1", 8888);

  buf_send_msg   = (char    *)malloc(STRING_BUFFER_SIZE);
  buf_recv_oled  = (char    *)malloc(500);
  buf_recv_audio = (int32_t *)malloc(2 * sizeof(int32_t));

  agent_state = WAITING_AGENT;

  esp_task_wdt_config_t wdt_config = {
      .timeout_ms = WDT_TIMEOUT_SEC * 1000,
      .idle_core_mask = 0,
      .trigger_panic = true};
  esp_task_wdt_reconfigure(&wdt_config);
  esp_task_wdt_add(NULL);
  log_i("Hardware init done. WDT=%ds. Waiting for micro-ROS agent...", WDT_TIMEOUT_SEC);
}

void loop() {
  esp_task_wdt_reset();
  switch (agent_state) {

  case WAITING_AGENT:
    EXECUTE_EVERY_N_MS(500,
      motor_safety_stop();
      if (!ETH.linkUp()) { log_w("Ethernet link down, waiting..."); } else {
          agent_state = (RMW_RET_OK == rmw_uros_ping_agent(100, 1))
                        ? AGENT_AVAILABLE : WAITING_AGENT;
          if (agent_state == AGENT_AVAILABLE) log_i("Agent found!");
      });
    break;

  case AGENT_AVAILABLE:
    agent_state = create_entities() ? AGENT_CONNECTED : WAITING_AGENT;
    if (agent_state == WAITING_AGENT) {
      destroy_entities();
    }
    break;

    case AGENT_CONNECTED:
      EXECUTE_EVERY_N_MS(2000,
        if (RMW_RET_OK == rmw_uros_ping_agent(200, 2)) {
          agent_ping_fail_count = 0;
          agent_state = AGENT_CONNECTED;
        } else {
          agent_ping_fail_count++;
          log_w("Agent ping failed %u/3", (unsigned int)agent_ping_fail_count);
          if (agent_ping_fail_count >= 3) {
            agent_state = AGENT_DISCONNECTED;
            log_w("Agent lost after repeated ping failures. Reconnecting...");
          }
        }
      );
      if (agent_state == AGENT_CONNECTED) {
        rcl_ret_t spin_rc = rclc_executor_spin_some(&executor, RCL_MS_TO_NS(10));
        if (spin_rc != RCL_RET_OK && spin_rc != RCL_RET_TIMEOUT) {
          log_w("executor spin error %d, forcing disconnect", (int)spin_rc);
          agent_state = AGENT_DISCONNECTED;
        }
      }
      break;

    case AGENT_DISCONNECTED:
      destroy_entities();
      agent_ping_fail_count = 0;
      set_microros_ethernet_udp_transports("192.168.10.1", 8888);
      delay(500);  // let network stack settle
      log_i("Transport re-registered. Entering WAITING_AGENT...");
      agent_state = WAITING_AGENT;
      break;

    default:
      agent_state = WAITING_AGENT;
      break;
  }
}

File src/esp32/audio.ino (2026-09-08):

#include <driver/i2s.h>

// https://github.com/pschatzmann/arduino-audio-driver
#include "AudioBoard.h"

/* ---------- I2C ---------- */
#define I2C_SDA 13
#define I2C_SCL 12
#define ES8311_ADDR 0x18

/* ---------- I2S ---------- */
#define I2S_MCK 8
#define I2S_BCK 11
#define I2S_WS 9
#define I2S_DO 46
#define I2S_DI 10

/* ---------- AMP ---------- */

AudioBoard board(AudioDriverES8311, NoPins);

void setup_i2s() {
  i2s_config_t i2s_config = {
      .mode = (i2s_mode_t)(I2S_MODE_MASTER | I2S_MODE_TX),
      .sample_rate = 44100,
      .bits_per_sample = I2S_BITS_PER_SAMPLE_16BIT,
      .channel_format = I2S_CHANNEL_FMT_ONLY_LEFT,
      .communication_format = I2S_COMM_FORMAT_STAND_MSB,
      .intr_alloc_flags = 0,
      .dma_buf_count = 8,
      .dma_buf_len = 128,
      .use_apll = true};

  i2s_pin_config_t pin_config = {
      .mck_io_num = 8,
      .bck_io_num = 11,
      .ws_io_num = 9,
      .data_out_num = 46,
      .data_in_num = 10};

  i2s_driver_install(I2S_NUM_0, &i2s_config, 0, NULL);
  i2s_set_pin(I2S_NUM_0, &pin_config);
}

void audio_init() {
  log_i("Starting audio initialization");

  CodecConfig cfg;

  cfg.input_device = ADC_INPUT_LINE1;
  cfg.output_device = DAC_OUTPUT_ALL;
  cfg.i2s.mode = MODE_SLAVE;
  cfg.i2s.fmt = I2S_NORMAL;
  cfg.i2s.rate = RATE_44K;
  cfg.i2s.bits = BIT_LENGTH_16BITS;
  cfg.i2s.channels = CHANNELS2;
  cfg.i2s.signal_type = SIGNAL_DIGITAL;

  log_i("Starting codec");

  bool ok = board.begin(cfg);

  if (ok) {
    log_i("Codec initialized successfully");
  } else {
    log_e("Codec initialization failed");
  }

  //!!!DO NOT RANDOMLY INCREASE THIS!!! - max. 50
  board.setVolume(45);

  delay(100);
  log_i("Calling setup_i2s");
  setup_i2s();
  log_i("Called setup_i2s");

  log_i("Starting audio task");
  xTaskCreatePinnedToCore(
      audioTask,
      "audio",
      4096,
      NULL,
      1,
      NULL,
      1);
  log_i("Started audio task");
}

volatile bool tone_active = false;
volatile float tone_freq = 440.0f;
volatile int samples_remaining = 0;
volatile float tone_phase = 0.0f;

void startTone(float freq, int duration_ms) {
  tone_freq = freq;
  samples_remaining = (44100 * duration_ms) / 1000;
  tone_phase = 0;
  tone_active = true;
}

//!!!DO NOT RANDOMLY INCREASE THIS!!! - max. 3000
#define AMPLITUDE 3000
void audioTask(void *param) {
  const int SAMPLE_RATE = 44100;
  const int BUFFER_SAMPLES = 128;

  int16_t buffer[BUFFER_SAMPLES];
  while (true) {

    if (tone_active) {

      float step = 2.0f * PI * tone_freq / SAMPLE_RATE;

      int n = BUFFER_SAMPLES;
      if (samples_remaining < n) n = samples_remaining;

      for (int i = 0; i < n; i++) {
        float sample_f = sinf(tone_phase) * (AMPLITUDE * 1.0f);

        if (samples_remaining < 50) {
          float fade = (float)samples_remaining / 50.0f;
          sample_f *= fade;
        }

        int16_t sample = (int16_t)sample_f;
        buffer[i] = sample;

        tone_phase += step;
        if (tone_phase >= 2.0f * PI) tone_phase -= 2.0f * PI;

        samples_remaining--;
      }

      size_t written;
      i2s_write(I2S_NUM_0, buffer, n * sizeof(int16_t), &written, portMAX_DELAY);

      if (samples_remaining <= 0) {
        tone_active = false;
      }

    } else {

      memset(buffer, 0, sizeof(buffer));

      size_t written;
      i2s_write(I2S_NUM_0, buffer, sizeof(buffer), &written, portMAX_DELAY);
    }
  }
}

/*
void loop() {
  startTone(660, 150);
  delay(180);
  startTone(880, 150);
  delay(5000);
}
*/

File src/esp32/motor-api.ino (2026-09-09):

#include <freertos/FreeRTOS.h>
#include <freertos/queue.h>
#include <freertos/task.h>

#define MOTOR_A_IN1_PIN 45
#define MOTOR_A_IN2_PIN 48
#define MOTOR_A_PWM_PIN 47

#define MOTOR_A_ENCODE1_PIN 14
#define MOTOR_A_ENCODE2_PIN 21

#define DIR_STOP 0
#define DIR_UP 1
#define DIR_DOWN 2
#define MOTOR_SPEED_MAX 400

#define LEDC_MAX_DUTY 8191
#define LEDC_MOTOR_A_CHANNEL 0
#define LEDC_MOTOR_TIMER 0

volatile int32_t encoder_ticks = 0;
volatile uint8_t encoder_last_state = 0;
volatile uint32_t encoder_invalid_transitions = 0;

static portMUX_TYPE encoder_ticks_mux = portMUX_INITIALIZER_UNLOCKED;

uint16_t motor_a_target_speed = 0;
int32_t motor_a_check_speed = 0;
uint8_t motor_a_dir = DIR_STOP;

struct MotorCommand {
  int32_t value;
  uint32_t received_ms;
};

static QueueHandle_t motor_command_queue = nullptr;

void IRAM_ATTR encoder_ISR() {
  uint8_t A = digitalRead(MOTOR_A_ENCODE1_PIN);
  uint8_t B = digitalRead(MOTOR_A_ENCODE2_PIN);
  uint8_t state = (A << 1) | B;

  portENTER_CRITICAL_ISR(&encoder_ticks_mux);

  uint8_t transition = (encoder_last_state << 2) | state;

  switch (transition) {
    // match the 202602 encoder convention, forward should increase ticks
    case 0b0001:
    case 0b0111:
    case 0b1110:
    case 0b1000:
      encoder_ticks--;
      break;

    case 0b0010:
    case 0b1011:
    case 0b1101:
    case 0b0100:
      encoder_ticks++;
      break;

    default:
      if (encoder_last_state != state) {
        encoder_invalid_transitions++;
      }
      break;
  }

  encoder_last_state = state;

  portEXIT_CRITICAL_ISR(&encoder_ticks_mux);
}
int32_t read_encoder_ticks() {
  portENTER_CRITICAL(&encoder_ticks_mux);
  int32_t ticks = encoder_ticks;
  portEXIT_CRITICAL(&encoder_ticks_mux);
  return ticks;
}

uint32_t read_encoder_invalid_transitions() {
  portENTER_CRITICAL(&encoder_ticks_mux);
  uint32_t invalid = encoder_invalid_transitions;
  portEXIT_CRITICAL(&encoder_ticks_mux);
  return invalid;
}

void motorA_pwm_init() {
  bool ok = ledcAttachChannel(
      MOTOR_A_PWM_PIN, 2000, 13, LEDC_MOTOR_A_CHANNEL);

  if (!ok) {
    error_loop("Failed to attach motor PWM channel");
  }
}

void motorA_io_init() {
  pinMode(MOTOR_A_IN1_PIN, OUTPUT);
  pinMode(MOTOR_A_IN2_PIN, OUTPUT);
  pinMode(MOTOR_A_PWM_PIN, OUTPUT);
}

void motorA_encoder_init() {
  pinMode(MOTOR_A_ENCODE1_PIN, INPUT_PULLUP);
  pinMode(MOTOR_A_ENCODE2_PIN, INPUT_PULLUP);

  uint8_t A = digitalRead(MOTOR_A_ENCODE1_PIN);
  uint8_t B = digitalRead(MOTOR_A_ENCODE2_PIN);

  portENTER_CRITICAL(&encoder_ticks_mux);
  encoder_last_state = (A << 1) | B;
  encoder_ticks = 0;
  encoder_invalid_transitions = 0;
  portEXIT_CRITICAL(&encoder_ticks_mux);

  attachInterrupt(digitalPinToInterrupt(MOTOR_A_ENCODE1_PIN), encoder_ISR, CHANGE);
  attachInterrupt(digitalPinToInterrupt(MOTOR_A_ENCODE2_PIN), encoder_ISR, CHANGE);
}

float GetSpeedInfo() {
  float distance = (float)read_encoder_ticks() /** (1000 / ENCODER_UPDATE_SPEED)*/ * 3.1416f * 65.0f / ((40.0f / 20.0f) * (11.0f * 4.0f) * 9.6f);
  return distance;
}

void Motor_A_SetLevel(uint8_t dir, uint16_t duty) {
  if (duty > LEDC_MAX_DUTY) duty = LEDC_MAX_DUTY;

  if (dir == DIR_UP) {
    digitalWrite(MOTOR_A_IN1_PIN, LOW);
    digitalWrite(MOTOR_A_IN2_PIN, HIGH);
  } else if (dir == DIR_DOWN) {
    digitalWrite(MOTOR_A_IN1_PIN, HIGH);
    digitalWrite(MOTOR_A_IN2_PIN, LOW);
  } else {
    digitalWrite(MOTOR_A_IN1_PIN, LOW);
    digitalWrite(MOTOR_A_IN2_PIN, LOW);
    duty = 0;
  }

  ledcWriteChannel(LEDC_MOTOR_A_CHANNEL, duty);
}

void Motor_A_Control(uint8_t dir, uint16_t speed) {
  if (speed > MOTOR_SPEED_MAX) speed = MOTOR_SPEED_MAX;

  motor_a_dir = dir;
  motor_a_target_speed = speed;

  uint16_t duty = map(speed, 0, MOTOR_SPEED_MAX, 0, LEDC_MAX_DUTY);

  Motor_A_SetLevel(dir, duty);
}

void motor_submit_command(int32_t value) {
  MotorCommand command = {constrain(value, -MOTOR_SPEED_MAX, MOTOR_SPEED_MAX), millis()};
  if (motor_command_queue != nullptr) {
    xQueueOverwrite(motor_command_queue, &command);
  }
}

void motor_command_task(void *) {
  MotorCommand command = {0, 0};
  int32_t applied = 0;
  for (;;) {
    xQueueReceive(motor_command_queue, &command, pdMS_TO_TICKS(10));
    int32_t value = command.value;
    if ((uint32_t)(millis() - command.received_ms) >= MOTOR_COMMAND_TIMEOUT_MS) {
      command.value = 0;
      value = 0;
    }
    if (value != applied) {
      uint8_t dir = value > 0 ? DIR_DOWN : value < 0 ? DIR_UP : DIR_STOP;
      Motor_A_Control(dir, (uint16_t)(value < 0 ? -value : value));
      applied = value;
    }
  }
}

void motor_init() {
  motorA_io_init();
  motorA_pwm_init();
  motorA_encoder_init();
  Motor_A_Control(DIR_STOP, 0);
  motor_command_queue = xQueueCreate(1, sizeof(MotorCommand));
  if (motor_command_queue == nullptr ||
      xTaskCreatePinnedToCore(motor_command_task, "motor_command", 2048, nullptr,
                              3, nullptr, 0) != pdPASS) {
    error_loop("Failed to start motor command watchdog");
  }
}

void encoder_check_speed() {
  motor_a_check_speed = (int32_t)GetSpeedInfo();
}

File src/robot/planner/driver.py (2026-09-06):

import math
import queue
import threading
import time
from collections import deque

import numpy as np
from rclpy.node import Node
from rclpy.qos import HistoryPolicy, QoSProfile, ReliabilityPolicy
from nav_msgs.msg import Odometry
from sensor_msgs.msg import Image, Imu, LaserScan
from std_msgs.msg import Float32MultiArray, Int32

from .config import DriverConfig
from .camera_color import ColorObstacle, color_obstacles, depth_image_m
from .debug import DebugFrame, DebugWindow
from .grid import Cell, Direction
from .localize_types import PoseEstimate
from .odometry_localize import OdometryLocalizer
from .graph_path import active_obstacle_component_mask, tracked_obstacle_overlap
from .obstacle_policy import ACTIVE_OBSTACLE_CLUSTER_RADIUS_M
from .planner import GridPlanner, Plan
from .sensors import SensorFrame, local_grid_from_scan, yaw_from_quat


def clamp(value: float, low: float, high: float) -> float:
    return max(low, min(high, value))


def sampled_path(points: tuple[tuple[float, float], ...], count: int = 6) -> str:
    if not points:
        return "[]"
    count = max(2, min(count, len(points)))
    last = len(points) - 1
    indices = (round(last * i / (count - 1)) for i in range(count))
    return "[" + ",".join(
        f"{points[i][0]:+.2f}:{points[i][1]:+.2f}" for i in indices
    ) + "]"


class PoseDebugLogger:
    def __init__(self) -> None:
        self.queue: queue.Queue[str] = queue.Queue(maxsize=8)
        self.stop_event = threading.Event()
        self.thread = threading.Thread(target=self._loop, daemon=True)
        self.thread.start()

    def write(self, line: str) -> None:
        try:
            self.queue.put_nowait(line)
        except queue.Full:
            try:
                self.queue.get_nowait()
            except queue.Empty:
                pass
            try:
                self.queue.put_nowait(line)
            except queue.Full:
                pass

    def stop(self) -> None:
        self.stop_event.set()
        self.thread.join(timeout=0.5)

    def _loop(self) -> None:
        while not self.stop_event.is_set():
            try:
                line = self.queue.get(timeout=0.05)
            except queue.Empty:
                continue
            print(line, flush=True)


class Driver(Node):
    def __init__(self):
        super().__init__("wro_planner")
        self.config: DriverConfig | None = None
        self.localizer: OdometryLocalizer | None = None
        self.planner: GridPlanner | None = None
        self.latest_scan: LaserScan | None = None
        self.latest_scan_received_at = 0.0
        self.latest_scan_sample_time = 0.0
        self.latest_scan_stamp = 0.0
        self.last_processed_scan_stamp = -math.inf
        self.latest_scan_sim_pose: tuple[float, float, float] | None = None
        self.latest_imu_yaw: float | None = None
        self.last_accepted_imu: tuple[float, float] | None = None
        self.latest_odometry: tuple[float, float, float, float] | None = None
        self.latest_odometry_speed_mps = 0.0
        self.imu_history: deque[tuple[float, float]] = deque(maxlen=64)
        self.odometry_history: deque[
            tuple[float, tuple[float, float, float, float]]
        ] = deque(maxlen=64)
        self.latest_frame: SensorFrame | None = None
        self.latest_plan: Plan | None = None
        self.latest_sim_pose: tuple[float, float, float] | None = None
        self.latest_sim_speed_mps = 0.0
        self.latest_camera_depth: tuple[np.ndarray, float] | None = None
        self.latest_camera_color: tuple[Image, float] | None = None
        self.last_camera_pair_stamp = -math.inf
        self.latest_camera_observation_time = 0.0
        self.latest_color_obstacles: tuple[tuple[ColorObstacle, ...], float] | None = None
        self.last_color_observation_time = 0.0
        self.debug_window: DebugWindow | None = None
        self.last_debug_render_ms = 0.0
        self.last_pose_debug_ms = 0.0
        self.state_lock = threading.Lock()
        self.debug_lock = threading.Lock()
        self.debug_frame: DebugFrame | None = None
        self.debug_thread: threading.Thread | None = None
        self.debug_stop = threading.Event()
        self.work_event = threading.Event()
        self.work_stop = threading.Event()
        self.work_thread: threading.Thread | None = None
        self.camera_event = threading.Event()
        self.camera_stop = threading.Event()
        self.camera_thread: threading.Thread | None = None
        self.work_busy = False
        self.last_motion_stamp: float | None = None
        self.last_prediction_blocked = False
        self.last_prediction_block_time_s = math.inf
        self.last_prediction_block_reason = "none"
        self.last_prediction_block_point: tuple[float, float] | None = None
        self.last_prediction_escape_cells = 0
        self.last_motor_command = 0
        self.last_motor_output = 0
        self.last_sensor_wait_reason = ""
        self.last_sensor_wait_log_time = -math.inf
        self.command_history: list[tuple[float, int, int]] = []
        self.pose_debug_logger: PoseDebugLogger | None = None
        self.motor_pub = None
        self.servo_pub = None

    def configure(
        self,
        config: DriverConfig,
        localizer: OdometryLocalizer,
        planner: GridPlanner,
        debug_window: DebugWindow | None = None,
    ) -> None:
        self.config = config
        self.localizer = localizer
        self.planner = planner
        self.debug_window = debug_window
        if self.debug_window is not None and config.debug_view_enabled:
            self.debug_thread = threading.Thread(target=self._debug_loop, daemon=True)
            self.debug_thread.start()
        if config.pose_debug:
            self.pose_debug_logger = PoseDebugLogger()
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

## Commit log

2026-07-05 Add code.
    [colours.xacro, inertial_macros.xacro, robot.urdf.xacro]
2026-09-08 Update code; fixing watchdog issues
    [audio.ino, esp32-code.ino, motor-api.ino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]
2026-09-09 fix esp32 bugs
